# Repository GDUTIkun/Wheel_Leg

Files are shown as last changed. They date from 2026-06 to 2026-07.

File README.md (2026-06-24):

# wheel_leg_project

当前仓库已按以下层次收口：

- `ros2_ws/`：正式 ROS2 工作区
- `firmware/`：STM32 固件
- `sim/`：MuJoCo 资源
- `scripts/`：统一 build/run 入口
- `docs/`：结构和迁移文档
- `transplant/`：迁移参考区

ROS2 构建产物固定放在 `ros2_ws/` 下：

- `ros2_ws/build`
- `ros2_ws/install`
- `ros2_ws/log`

这样 `ros2_ws/` 只承担 ROS2 workspace 职责，避免和 `firmware/`、`sim/`、`scripts/` 混放。

常用命令：

```bash
./scripts/build.sh core
./scripts/build.sh sim
./scripts/build.sh pi
./scripts/run_host.sh sim
./scripts/run_host.sh sim_only
./scripts/run_pi.sh rc
./scripts/run_pi.sh hw
```

完整文档入口见：

- [docs/README.md](docs/README.md)

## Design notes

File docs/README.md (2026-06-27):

# 文档入口

当前 `docs/` 只保留正在使用的主线文档。历史迭代拆分、旧任务清单和重复规划文档已经移除，避免后续按过期内容继续推进。

## 当前主线

- `progress.md`：当前阶段进度与待确认问题。
- `stm32_hardware_integration.md`：STM32 硬件接入与实机闭环准备。
- `stm32_ros_comm_task.md`：STM32 与 ROS 第一版通信内容、字段和验收任务。
- `control_stm_migration_plan.md`：控制层接入 STM 的分层、阶段开关、测试顺序和进度表。
- `hardware_control_200hz.md`：当前 `200Hz` 实机控制口径、参数修改和频率说明。
- `100hz_balance_notes.md`：500Hz 调整到 100Hz 后的仿真平衡记录，作为上硬件前参考基线。
- `leg_angle_mapping.md`：腿部 GIM6010 电机角度到机构角/世界水平角的标定映射。

## 长期约束

- `architecture.md`：仓库结构、ROS2 包边界、仿真/实机切换原则。
- `protocol.md`：仿真和实机共用的 Topic、命名、单位、方向和通信边界。
- `runbook.md`：构建、启动和常用运行入口。

## 维护规则

- 新阶段只更新 `progress.md` 和对应的当前任务文档。
- 已完成阶段只保留对后续调试仍有直接价值的总结。
- 不再新增 `docs/doc/` 这类平行文档体系。

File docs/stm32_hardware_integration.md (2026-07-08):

# STM32 硬件接入与实机闭环任务

## 1. 任务目标

在 100Hz 仿真平衡基线已经可以站稳的基础上，进入 STM32 / 实机硬件接入阶段。

本任务的目标不是立刻完成最终实机参数，而是先打通真实硬件状态上报、控制命令下发、安全保护和基础方向校验，让后续 100Hz 实机调参有可靠输入。

## 2. 当前输入

- 100Hz 仿真可站立基线。
- `100hz_balance_notes.md` 中记录的传感器、滤波、LQR 和执行器输出处理原则。
- 已冻结的 RC 遥控输入与 failsafe 链路。
- 当前 ROS2 控制接口与仿真接口边界。
- STM32 侧电机、编码器、IMU 和底层安全保护能力。

## 3. 当前状态

- `[~]` 进入 STM32 / 实机硬件接入阶段。
- `[!]` 100Hz 仿真参数等待硬件接入后重新调参。

当前判断：

- 100Hz 仿真已能稳定站立，先作为可运行基线冻结。
- 当前不继续只在仿真中追求最终参数。
- 实机参数应在真实 IMU、编码器、电机响应和通信延迟接入后重新小步调整。

## 4. 重点任务

1. 通信链路
   - Raspberry Pi 与 STM32 的通信收发稳定。
   - 能观察通信周期、丢包、超时和错误计数。

2. 状态上报
   - 编码器角度、角速度、电机反馈状态可映射到 ROS2。
   - IMU 姿态和角速度可映射到 ROS2。
   - 单位统一为控制器期望的 `rad`、`rad/s`、`m/s`、`N*m` 等口径。

3. 命令下发
   - `/joint_command` 能下发到 STM32。
   - 电机命令方向、限幅、斜率限制和停机行为可验证。
   - 控制器不直接依赖 STM32 协议细节。

4. 安全保护
   - 通信超时进入安全状态。
   - 遥控 failsafe 可以阻断或降级控制输出。
   - 电机输出有明确最大值和变化率限制。
   - 初次调试支持悬空、低力矩、单关节验证。

5. 100Hz 实机闭环准备
   - 实测控制周期接近 `0.01s`。
   - 周期抖动可记录。
   - 传感器滤波和速度估计使用实际 `dt`。

## 5. 上硬件前检查

上硬件前至少确认：

- pitch 正方向与仿真一致。
- pitch_rate 正方向与 LQR 状态定义一致。
- 当前角度解算口径：角度由角速度积分得到；实机观测为向左转动角度正向增加，向右转动角度反向减小。
- 左右腿 `phi` 与 `phi_rate` 方向一致。
- 轮子前进方向与 `base_link.velocity` 正方向一致。
- STM32 上报的髋关节和小腿角已经是世界坐标系 absolute 角，bridge 不再叠加仿真 offset。
- `/robot_state` 中 `hip_absolute`、`calf_absolute` 与实物世界角一致。
- VMC 输出到电机后的力矩方向正确。
- 电机最大力矩和变化率不比仿真基线更激进。
- 控制使能前，滤波器状态能初始化到当前测量值。
- 急停、failsafe、通信超时都有可验证行为。

## 6. 初期调参原则

- 先悬空验证方向，再轻触地验证支撑力，最后再尝试站立。
- 先小力矩、小命令、短时间闭环，不直接恢复完整速度和转向能力。
- 先确认 `pitch_rate`、`phi_rate`、`base_velocity` 可信，再调 LQR 增益。
- 若出现 pitch 高频震荡，优先检查 IMU 方向、gyro 滤波、`pitch_rate` 增益和执行器斜率限制。
- 若出现缓慢前后跑偏，优先检查 `target_phi`、`target_pitch`、速度方向和距离积分。
- 若出现单侧压低，优先检查左右腿角度、roll、VMC 映射和左右电机方向。
- 若出现“仅单侧在某一方向或接近 `phi_target` 时更容易高频抖动”，不要只检查力矩极性；应同时记录该侧 `phi_rate`、髋膝关节速度和 `/joint_command`，优先排查目标附近闭环阻尼、单边速度状态过大、速度估计噪声、执行死区、机械回差或线束干涉。

## 7. 每轮记录模板

```text
- 轮次：
- 硬件状态：
- 修改参数/代码：
- 测试动作：
- 观察数据：
- 安全状态：
- 结论：
- 下一步：
```

## 8. 阶段完成标准

- STM32 通信链路稳定可观测。
- 真实传感器状态与 ROS2 状态接口语义一致。
- 电机命令方向、单位、限幅和安全停机已验证。
- 100Hz 实际控制周期和 `dt` 处理已确认。
- 可以在低风险条件下进入实机站立闭环参数调整。

## 9. 通信完成后的测试方法与流程

通信测试完成后，当前阶段不直接进入整机闭环，而是先做“悬空低力矩单关节验证”。

目标：

- 验证 `/joint_command -> bridge -> STM32 -> 电机` 下行链路持续有效。
- 验证六电机方向、单位、限幅和停机行为。
- 验证 `/joint_states`、`/imu`、`/robot_state` 的上行观测与实际动作一致。
- 验证 `RC ch7` 急停、命令超时和 bridge 侧状态监控工作正常。

### 9.1 测试前准备

执行前先确认：

- 机器人处于悬空或可靠支撑状态，轮子和腿部不会意外着地。
- 电机周围无工具、线缆和手部干涉。
- 树莓派与 STM32 已共地。
- 串口设备仍为 `/dev/ttyAMA4`，STM32 对应 `USART2`。
- 遥控器已上电，`RC ch7` 急停动作明确可用。
- bridge、STM32 固件和当前协议版本一致。
- 首次测试保持小力矩，例如 `0.1 ~ 0.2 N*m`。

### 9.2 启动流程

1. 启动正式 bridge，但先关闭控制器，避免 `/joint_command` 被控制器覆盖：

```bash
ros2 launch wheel_leg_bringup hw.launch.py use_controller:=false command_enable:=true
```

2. 在第二个终端观察 bridge 状态：

```bash
ros2 topic echo /stm32_bridge/status_text
```

3. 在第三个终端观察 bridge 计数器：

```bash
ros2 topic echo /stm32_bridge/counters
```

4. 在第四个终端观察关节反馈：

```bash
ros2 topic echo /joint_states
```

5. 如需同时观察机体状态，可额外打开：

```bash
ros2 topic echo /robot_state
```

### 9.3 单关节低力矩命令发送

当前推荐使用 `joint_command_probe_node` 做单关节验证。

固定正向小力矩示例：

```bash
ros2 run wheel_leg_stm32_bridge joint_command_probe_node --ros-args \
  -p joint_name:=left_hip \
  -p effort_nm:=0.2 \
  -p publish_rate_hz:=20.0 \
  -p mode:=constant
```

正负交替方波示例：

```bash
ros2 run wheel_leg_stm32_bridge joint_command_probe_node --ros-args \
  -p joint_name:=left_hip \
  -p effort_nm:=0.2 \
  -p publish_rate_hz:=20.0 \
  -p mode:=square \
  -p square_period_sec:=2.0
```

参数说明：

- `joint_name`：目标关节名，只允许规范名
- `effort_nm`：目标力矩幅值，建议从 `0.1` 或 `0.2` 开始
- `publish_rate_hz`：重复下发频率，当前建议 `20Hz`
- `mode=constant`：持续给定单一方向力矩
- `mode=square`：按周期在正负力矩之间切换
- `square_period_sec`：方波完整周期

### 9.4 推荐测试顺序

建议按以下顺序逐个测试，每次只动一个关节，其余五路保持零力矩：

1. `left_hip`
2. `left_knee`
3. `left_wheel`
4. `right_hip`
5. `right_knee`
6. `right_wheel`

每个关节建议按同样步骤执行：

1. 先用 `mode=constant` 验证正向小力矩。
2. 观察动作方向与 `/joint_states.velocity` 正方向是否一致。
3. 再改成负向小力矩，确认反向动作。
4. 最后用 `mode=square` 做短时间正负切换，观察限幅、响应和停机恢复是否稳定。

### 9.5 现场观察项

每轮测试至少观察以下内容：

- `/stm32_bridge/status_text` 中应保持 `state=ok`、`state_stale=false`
- `/stm32_bridge/counters` 中 `rx_frames_ok` 应持续增长
- `/stm32_bridge/counters` 中 `rx_crc_errors`、`rx_length_errors`、`rx_sync_losses` 不应明显持续增长
- `/joint_states` 中目标关节的位置和速度应与实际动作一致
- `/robot_state` 中与该动作相关的量不应出现明显跳变或异常漂移
- 若切到反向力矩，实际动作和速度符号也应同步反向
- 目标关节外的其他五个关节不应出现危险联动

### 9.6 安全项验证

在单关节方向确认后，必须补做以下安全验证：

1. 急停验证

- 维持单关节小力矩输出。
- 触发 `RC ch7` 急停。
- 预期行为：
  - bridge 状态中的 `estop=true`
  - 下行 `enable=0`
  - 电机输出立即归零或失能
  - 关节停止继续加速

2. 命令超时验证

- 关闭 `joint_command_probe_node`。
- 在 STM32 命令超时窗口后观察：
  - `safety=timeout` 或等价安全状态出现
  - 电机输出归零或失能
  - `last_command_timeout` 相关状态可观测

3. 限幅与斜率限制验证

- 将 `effort_nm` 从 `0.1` 逐步增加到 `0.2`、`0.3`
- 不直接大步跳到高力矩
- 观察实际响应是否平滑，是否存在异常冲击

### 9.7 异常时处理顺序

若测试中出现异常，按以下顺序排查：

1. 立即触发急停或关闭探针节点。
2. 确认机器人仍保持悬空和安全状态。
3. 查看 `/stm32_bridge/status_text` 是否变为 `state_stale=true`、`safety=timeout`、`estop=true` 等。
4. 查看 `/stm32_bridge/counters` 是否出现 CRC、长度、同步错误快速增长。
5. 若动作方向与预期相反，先记录关节名、正负力矩方向、实际动作方向，再回到映射层修正。
6. 若目标关节不动但计数器正常，优先排查 STM32 执行层、限幅、使能位和电机在线状态。
7. 若上行状态异常漂移，优先排查编码器零点、方向、IMU 方向和单位映射。

### 9.8 单轮记录建议

每个关节验证完成后，建议按下面格式记录：

```text
- 轮次：left_hip constant +0.2Nm
- 硬件状态：悬空 / 共地正常 / UART4<->USART2
- 修改参数/代码：无
- 测试动作：20Hz 持续下发 left_hip +0.2Nm
- 观察数据：joint_states.velocity 为正，bridge counters 正常
- 安全状态：RC ch7 急停有效，停止后 timeout 生效
- 结论：left_hip 正方向确认
- 下一步：验证 left_hip -0.2Nm 和 square 模式
```

### 9.9 2026-06-25 极性测试记录

本轮已完成一次六电机悬空极性验证，测试期间 bridge 通信保持正常，验证后已手动停机。

记录如下：

```text
- 日期：2026-06-25
- 硬件状态：机器人悬空 / UART4<->USART2 正常 / bridge state=ok
- 修改参数/代码：
  - 不修改 STM32 侧代码
  - 在 ROS bridge 下行命令路径加入轮子力矩极性修正
  - 修改文件：
    ros2_ws/src/wheel_leg_stm32_bridge/src/stm32_bridge_node.cpp
  - 新增下行符号表 kCommandEffortSigns
  - 轮子修正前：
    left_wheel=+1
    right_wheel=+1
  - 轮子修正后：
    left_wheel=-1
    right_wheel=-1
- 测试方式：
  - 使用 joint_command_probe_node 逐个关节下发恒定力矩
  - 六电机验证采用每路持续 5s 的方式现场观察转向
  - 轮子为便于观察，单独补做了 5s、6s、10s 的重复测试
- 现场结论：
  - 极性测试完毕
  - 轮子最终不修改 STM32 侧代码，只在 ROS bridge 下行力矩处做极性修正
  - 当前 ROS->STM32 下行力矩符号表为：
    left_hip=+1
    left_knee=+1
    left_wheel=-1
    right_hip=+1
    right_knee=+1
    right_wheel=-1
  - 对应实现位置：
    ros2_ws/src/wheel_leg_stm32_bridge/src/stm32_bridge_node.cpp
- 安全状态：
  - 每轮测试结束后 probe 节点退出
  - bridge 在测试完成后手动停止
  - 测试窗口内未观察到 bridge CRC / 长度 / 同步错误持续增长
```

后续若继续修正髋、膝或轮子的方向定义，应优先修改 ROS bridge 的下行力矩符号表，不直接把安装方向差异泄漏到上层控制器。

### 9.10 2026-06-25 RC / Timeout / 状态频率验收记录

本轮补做了通信部分剩余三项验收：`RC ch7` 急停整链、命令超时链路、以及 `/robot_state` `/imu` `/joint_states` 的时间戳与频率检查。

记录如下：

```text
- 日期：2026-06-25
- 前提修正：
  - RC 急停方向改为“高位急停”
  - estop.active_below 默认值由 true 改为 false
  - estop.threshold 默认值由 1500.0 调整为 1700.0
  - rc.launch.py 增加 estop_threshold launch 参数
  - 曾出现一次 RC 链路异常，现场确认为树莓派供电不足；恢复供电后重测
  - 曾出现 /rc/status 双发布者污染；清理重复 rc.launch 后按单发布者结果验收

- RC ch7 -> /rc/status.estop_active -> bridge -> STM32 safety_state：
  - 持续命令下抓到 bridge 状态从 safety=enabled 切换到 safety=estop
  - 同时 /rc/status.estop_active 与 bridge status_text 中 estop=true 对应变化一致
  - 该整链硬件验证通过

- 命令超时链路：
  - 在 estop_active=false 前提下，先持续发送单关节小力矩命令约 3s
  - bridge status_text 先进入：
    state=ok state_stale=false command_stale=false command_enable=true safety=enabled estop=false
  - 停止发送命令后，bridge status_text 回到：
    state=ok state_stale=false command_stale=true command_enable=true safety=timeout estop=false
  - 说明 STM32 命令超时保护链路工作正常，该项验收通过

- /robot_state /imu /joint_states 时间戳与频率：
  - /robot_state:
    header_dt_mean ≈ 0.01524 s
    approx_hz ≈ 65.99 Hz
  - /imu:
    header_dt_mean ≈ 0.01524 s
    approx_hz ≈ 65.65 Hz
  - /joint_states:
    header_dt_mean ≈ 0.01524 s
    approx_hz ≈ 65.62 Hz
  - 当前状态发布频率约 66 Hz，未达到 100 Hz / 0.01 s 目标
  - 该项结论应记录为“当前口径已测得，但仍需后续优化到 100 Hz 目标”

- RC 链路复查：
  - 在最终 10s 稳定窗口内：
    estop_active=false
    failsafe=false
    serial_online=true
    receiver_online=true
    frame_timeout=false
  - checksum_error_count 未增长
  - frame_sync_loss_count 未增长
```

当前通信部分剩余结论：

- `RC ch7` 急停整链：已验证通过
- 命令超时链路：已验证通过
- 状态发布时间戳 / dt / 频率：已测得当前约 `66 Hz`，但尚未达到 `100 Hz`

### 9.11 通过标准

通信完成后的这一步，至少满足以下条件才进入下一阶段：

- 六个关节都完成单关节小力矩方向验证
- `/joint_states` 与实际运动方向一致
- bridge 计数器在测试窗口内稳定
- 急停和命令超时都已验证
- 未出现危险联动、异常冲击或持续通信错误

满足以上条件后，再进入“轻触地验证”和后续低风险实机闭环调参。

### 9.12 2026-06-26 ROS 侧关节限位高力矩急停保护

本轮在 ROS bridge 侧补充了一条本地保护，不修改 STM32 侧代码。

记录如下：

```text
- 日期：2026-06-26
- 修改位置：
  ros2_ws/src/wheel_leg_stm32_bridge/src/stm32_bridge_node.cpp
- 触发条件：
  - 使用 STM32 状态帧回传的实际 joint_position / joint_effort 做判断
  - 当关节到达限位，并且该关节实际回传力矩绝对值 > 3.0 Nm 时
  - ROS bridge 触发本地 local estop，并立即向 STM32 下发 estop 命令帧
- 当前默认限位口径：
  - hip 使用世界角：
    left_hip  = 75 ~ 200 deg
    right_hip = 75 ~ 200 deg
  - knee 使用相对角，不叠加 hip：
    left_knee_relative  = -140 ~ -70 deg
    right_knee_relative = -140 ~ -70 deg
- 默认阈值来源：
  - docs/leg_angle_mapping.md
  - 其中明确记录：
    hip_world_range = 75 ~ 200
    knee_relative_range = -140 ~ -70
- 当前实现说明：
  - 该保护为 ROS 侧锁存急停；触发后即使后续命令继续下发，也会继续按 estop 发送
  - /stm32_bridge/status_text 会额外显示：
    local_estop=true
    local_estop_reason=...
  - 当前未实现自动解除，需要重启节点或后续再补显式复位机制
```

当前这条保护的目的不是替代 STM32 侧安全停机，而是在 ROS 侧增加一层“到限位仍持续顶力矩”的联调保护，降低悬空调试和轻触地调试阶段的风险。

### 9.13 2026-07-07 LQR 调参收口记录

本轮在 LQR + VMC 悬空方向复核完成后，对目标附近腿角闭环做保守化处理，并结束本轮 LQR 调参。

记录如下：

```text
- 日期：2026-07-07
- 修改位置：
  ros2_ws/src/wheel_leg_control/src/legacy_algorithms.cpp
  ros2_ws/src/wheel_leg_control/src/controller_node.cpp
  ros2_ws/src/wheel_leg_bringup/config/control_hw.yaml
- LQR 状态顺序：
  [phi, phi_rate, distance, velocity, pitch, pitch_rate]
- 输出语义：
  - 第一行取反后作为 VMC 腿摆杆虚拟力矩
  - 第二行作为轮端力矩
- 调参收口：
  - 髋部输出行的 phi / phi_rate 增益乘 0.6
  - 轮端输出行不乘该系数
  - 新增 phi_rate_damping_kd，硬件默认 -0.2
  - phi_rate_damping_kd 只追加到髋部虚拟力矩，不作用于轮端力矩
- 验证：
  - wheel_leg_control 单元测试通过
  - 新增测试覆盖“phi/phi_rate 缩放只影响髋部输出行”和“phi_rate_damping_kd 不影响 wheel_torque”
- 结论：
  - 本轮 LQR 调参结束
  - 后续轻触地/落地阶段不继续盲目改 LQR 增益
  - 若仍有目标附近局部抖动，优先查速度估计、执行死区/回差、静摩擦释放、线束干涉、限幅和斜率限制
```

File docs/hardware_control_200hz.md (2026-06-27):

# `200Hz` 实机控制口径记录

本文档记录自 `2026-06-27` 起，仓库主线硬件闭环采用的 `200Hz` 控制口径，避免继续把“`100Hz` 仿真基线”和“`200Hz` 实机联调口径”混在一起。

## 1. 当前结论

- STM32 `Data_Task` 以 `5ms` 周期运行，对应 `200Hz`。
- STM32 正式状态帧 `type=0x81` 已实测稳定跑到 `200Hz`。
- ROS 侧 `wheel_leg_stm32_bridge` 收到一帧状态就立即发布一次：
  - `/robot_state`
  - `/imu`
  - `/joint_states`
- ROS 侧 `wheel_leg_controller` 由 `/robot_state` 驱动，每收到一个满足 `dt` 条件的新样本就执行一步控制，并发布一次 `/joint_command`。
- 当前硬件参数已切到 `expected_dt_sec = 0.005`，即按 `200Hz` 接受控制样本。

## 2. 本次落地修改

本次仅切换**硬件主线**到 `200Hz`：

- 修改文件：`ros2_ws/src/wheel_leg_bringup/config/control_hw.yaml`
- 修改内容：
  - `debug_plot_publish_hz: 200.0`
  - `expected_dt_sec: 0.005`
  - `accepted_dt_tolerance_sec: 0.002`

当前 `accepted_dt_tolerance_sec = 0.002` 的接受窗口为：

- 最小 `dt = 0.003s`
- 最大 `dt = 0.007s`

该窗口用于覆盖串口、ROS 调度和时间戳抖动，但仍明确拒绝明显偏离 `200Hz` 主线的样本。

## 3. 当前频率口径

### 3.1 STM32 侧

- IMU 快照读取：`200Hz`
- 正式状态帧上报：`200Hz`
- 控制命令执行刷新：跟随下行 `/joint_command` 更新

### 3.2 ROS 硬件链

- `/robot_state`：约 `200Hz`
- `/imu`：约 `200Hz`
- `/joint_states`：约 `200Hz`
- `wheel_leg_controller` 有效控制步频：目标 `200Hz`
- `/joint_command`：目标 `200Hz`

### 3.3 RC 链

- `rc_ibus_node` 串口轮询周期：`5ms`，约 `200Hz`
- `/rc/channels_raw`：随有效遥控帧发布，通常接近 `200Hz`
- `/cmd_vel`、`/control_mode`、`/body_cmd`：随有效遥控帧更新
- `/rc/status`：`100ms`，即 `10Hz`

## 4. 与 `100Hz` 仿真基线的关系

以下内容**保持不变**：

- `100hz_balance_notes.md` 仍然是当前仿真平衡基线
- `control_sim.yaml` 仍按 `expected_dt_sec = 0.01` 运行
- MuJoCo 仿真主线仍是 `100Hz`

也就是说，当前仓库口径变为：

- 仿真主线：`100Hz`
- 实机硬件闭环主线：`200Hz`

后续如果需要把仿真也切到 `200Hz`，应单独立项，不要直接复用这次硬件参数切换结论。

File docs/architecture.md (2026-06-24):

# 轮腿机器人工程结构整改架构文档

## 1. 文档目标

本文档用于固定 STM32 接入前的正式工程结构，约束仓库目录、ROS2 包边界、构建入口和仿真/实机切换方式。

本文档服务于两个直接目标：

- 多设备同步同一仓库进度，但不同设备只构建自己需要的部分。
- 在不重写控制主链的前提下，为后续仿真/实机顺滑切换和 `ros2_control` 接入预留结构。

## 2. 总体原则

- 采用单仓库组织，不拆分为多个仓库。
- ROS2 代码统一收口到 `ros2_ws/src/`。
- 固件、仿真资源、脚本、文档与 ROS2 包分层存放。
- `transplant/` 仅作为迁移参考区，不承载新增正式能力。
- 当前阶段继续保持 Topic 闭环主线，不在本轮直接重构为完整 `ros2_control`。

## 3. 目标目录结构

```text
wheel_leg_project/
├── ros2_ws/
│   ├── src/
│   │   ├── wheel_leg_msgs/
│   │   ├── wheel_leg_control/
│   │   ├── wheel_leg_bringup/
│   │   ├── wheel_leg_hw/
│   │   ├── wheel_leg_stm32_bridge/
│   │   ├── wheel_leg_sim/
│   │   ├── wheel_leg_rc/
│   │   ├── wheel_leg_common/
│   │   └── wheel_leg_bridge/
│   ├── build/
│   ├── install/
│   └── log/
├── firmware/
│   └── stm32/
├── sim/
│   └── mujoco/
│       ├── runtime/
│       ├── models/
│       ├── scenes/
│       ├── assets/
│       └── README.md
├── scripts/
│   ├── build.sh
│   ├── run.sh
│   ├── flash_stm32.sh
│   └── env.sh
├── docs/
│   ├── README.md
│   ├── architecture.md
│   ├── protocol.md
│   ├── runbook.md
│   ├── progress.md
│   ├── stm32_hardware_integration.md
│   └── 100hz_balance_notes.md
├── transplant/
└── README.md
```

## 4. 各层职责

### 4.1 `ros2_ws/`

ROS2 正式开发工作区。

约束：

- 所有正式 ROS2 包只放在 `ros2_ws/src/`。
- `build/ install/ log/` 只存在于 `ros2_ws/` 内。
- 不在仓库根目录直接堆放新的 ROS2 包。

### 4.2 `firmware/stm32/`

STM32 固件区。

职责：

- 存放 STM32 工程、驱动、中断、协议处理和板级配置。
- 作为树莓派侧通信协议的对端实现。

约束：

- 不放 ROS2 包。
- 不放 MuJoCo 仿真逻辑。

### 4.3 `sim/mujoco/`

MuJoCo 模型和场景资源区。

职责：

- `runtime/`：MuJoCo 可执行仿真程序源码与构建入口。
- `models/`：机器人主体模型定义。
- `scenes/`：场景入口文件。
- `assets/`：网格、材质和贴图等资源。

约束：

- 仿真资源和 ROS2 包解耦。
- 不把模型文件继续埋在 `transplant/` 里作为正式入口。
- 不把仿真程序入口继续留在 `transplant/` 里。

### 4.4 `scripts/`

统一开发入口。

职责：

- 统一 `build` 和 `run` 的用户操作。
- 按设备和场景选择性构建。
- 固化环境变量和常用命令，降低协作摩擦。

### 4.5 `docs/`

正式文档区。

职责：

- 维护结构、协议、运行入口、当前进度和当前阶段任务文档。
- 保留对后续硬件接入仍有直接价值的调参记录。
- 不再维护旧的 `docs/doc/` 平行规划体系。

### 4.6 `transplant/`

迁移参考区。

职责：

- 保留旧 MuJoCo 工程、算法参考、早期实验材料。

约束：

- 不继续往这里写正式新代码。
- 默认不作为正式构建入口。

## 5. ROS2 包职责

### 5.1 `wheel_leg_msgs`

- 维护自定义消息。
- 统一 `/joint_command`、`/robot_state`、遥控相关消息定义。

### 5.2 `wheel_leg_control`

- 维护控制编排、状态处理、控制算法调用。
- 长期不直接依赖 MuJoCo API、串口实现、STM32 协议细节。

### 5.3 `wheel_leg_bringup`

- 维护 launch、参数装配、仿真/实机入口切换。
- 负责把同一套控制主链接到不同 backend。

### 5.4 `wheel_leg_hw`

- 维护统一硬件抽象。
- 固定 joint、imu、actuator 的命名、单位和语义。
- 作为后续 `ros2_control` 接口收口点。

### 5.5 `wheel_leg_stm32_bridge`

- 维护树莓派与 STM32 的通信节点。
- 负责协议编解码、状态上送、控制命令下发。

### 5.6 `wheel_leg_sim`

- 维护 MuJoCo 运行时适配。
- 负责仿真状态采样、命令写入和 sim-only helper。

### 5.7 `wheel_leg_rc`

- 维护遥控器输入接入与统一命令发布。

### 5.8 `wheel_leg_common`

- 维护共享类型、数学工具、命名映射和轻量公共结构。

### 5.9 `wheel_leg_bridge`

- 保留现有消息转换和通信边界胶水代码。
- 在过渡期继续服务现有主链。

## 6. 控制主链与切换原则

当前阶段统一主链固定为：

```text
state source -> /robot_state -> wheel_leg_controller -> /joint_command -> actuator sink
```

### 6.1 仿真模式

- `wheel_leg_sim` 发布 `/robot_state`
- `wheel_leg_controller_node` 订阅 `/robot_state`
- `wheel_leg_controller_node` 发布 `/joint_command`
- `wheel_leg_sim` 消费 `/joint_command`

### 6.2 实机模式

- `wheel_leg_stm32_bridge` 发布 `/robot_state`
- `wheel_leg_controller_node` 订阅 `/robot_state`
- `wheel_leg_controller_node` 发布 `/joint_command`
- `wheel_leg_stm32_bridge` 消费 `/joint_command`

切换时不更换控制器，只更换状态源和命令去向。

## 7. 与 `ros2_control` 的关系

本轮不直接迁到完整 `ros2_control`，但结构必须为后续接入预留。

后续目标：

- MuJoCo 对接 `WheelLegMujocoSystem`
- STM32 对接 `WheelLegSTM32System`
- 控制器视情况迁成 controller plugin，或保留外部节点过渡

本轮必须先固定：

- joint 命名
- imu 命名
- actuator 命名
- 单位
- 方向
- 零位约定

## 8. 当前状态说明

当前仓库已经完成的结构性动作：

- 原 `src/` 已迁入 `ros2_ws/src/`
- 原 `build/ install/ log/` 已迁入 `ros2_ws/`
- 旧 `docs/doc/` 拆分文档已清理，当前只保留 `docs/` 根目录主线文档

后续重构应基于本文件继续推进，不再回到“根目录直接堆 ROS2 工作区产物”的方式。

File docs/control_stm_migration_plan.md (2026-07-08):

# 控制层接入 STM 迁移计划

## 1. 目标与边界

第一阶段采用 `ROS2 控制 + STM32 硬件后端`：

- `wheel_leg_control` 继续运行 VMC、LQR、航向、抗劈叉和 roll 补偿。
- `wheel_leg_stm32_bridge` 负责 STM32 协议编解码、状态映射、命令下发和 ROS 侧安全保护。
- `firmware/stm32` 负责真实传感器采样、电机执行、力矩限幅、斜率限制、命令超时和急停。
- 本阶段不把 VMC/LQR 下沉到 STM32，也不迁入完整 `ros2_control`。

公共主链保持不变：

```text
backend -> /robot_state -> wheel_leg_controller -> /joint_command -> backend
```

仿真和硬件只替换 backend：

- 仿真：`wheel_leg_sim` 发布 `/robot_state` 并消费 `/joint_command`
- 硬件：`wheel_leg_stm32_bridge` 发布 `/robot_state` 并消费 `/joint_command`

## 2. 分层与代码对应

| 层级 | 职责 | 主要代码 | 当前状态 |
| --- | --- | --- | --- |
| 控制阶段门控 | 按传感器、VMC、LQR、航向、抗劈叉、roll 逐段打开控制输出 | `wheel_leg_control` | `[v] LQR+VMC 悬空方向已验证，[~] 落地稳定性待验证` |
| 仿真参数入口 | 保持仿真全功能默认配置 | `wheel_leg_bringup/config/control_sim.yaml` | `[x] 代码已完成` |
| 硬件参数入口 | 当前硬件默认进入 LQR 阶段，VMC/LQR/腿长 PID/轮端/髋膝输出均开启，辅助环仍关闭 | `wheel_leg_bringup/config/control_hw.yaml` | `[x] 代码已完成，[~] 落地待验证` |
| 硬件状态装配 | 将 STM32 absolute 世界角/IMU 数据映射到控制器语义 | `wheel_leg_stm32_bridge/hardware_state_assembler` | `[x] 代码已完成，[!] 待实机验证` |
| STM32 协议与执行 | 状态帧、命令帧、限幅、斜率、超时、急停 | `wheel_leg_stm32_bridge` / `firmware/stm32` | `[~] 联调中` |

`wheel_leg_control` 不解析 STM32 二进制协议；STM32、串口、CAN 细节不得泄漏到控制层。

硬件腿部角度口径：

- 仿真侧仍由原始关节角叠加 offset 得到 `hip_absolute`、`calf_absolute`。
- STM32 上报到 bridge 的髋和小腿角已经是世界坐标系 absolute 角，bridge 不再叠加仿真 offset。
- 状态帧中的 `left_knee` / `right_knee` 位置槽位在控制语义里作为 `left_calf_absolute` / `right_calf_absolute` 使用。
- 腿部机构不是串联二连杆，不能使用 `hip_absolute + calf_absolute - pi` 推下连杆角。
- 腿部几何按实物平行四边形语义计算：`delta = hip_absolute - calf_absolute`，`knee_angle = pi - delta`，`lower_link_absolute = hip_absolute - pi + knee_angle`，再用大小腿三角形求腿对角边 `leg_length` 与世界系腿角 `phi`。
- `phi_rate` 由修正后的 `phi` 做角度差分和低通滤波。
- VMC 的髋/膝力矩映射已按同一套几何复核，避免 `phi/leg_length` 已修正但雅可比仍沿用旧串联模型。

## 3. 控制阶段参数

控制器新增以下参数，仿真默认全开；当前硬件默认配置已进入 LQR 阶段：

- 已开启：`VMC`、`LQR`、腿长 PID、轮端输出、髋/膝输出。
- 仍关闭：航向控制、抗劈叉、roll 补偿。
- `hw.launch.py` 默认 `command_enable=false`，即 ROS 内部会计算 `/joint_command`，但 bridge 不会向 STM32 下发实际非零力矩，除非显式改为 `command_enable:=true`。

| 参数 | 作用 | 硬件默认 |
| --- | --- | --- |
| `enable_vmc` | 启用腿端力/髋力矩到髋膝电机力矩的 VMC 映射 | `true` |
| `enable_lqr` | 启用 LQR 计算轮端力矩和髋关节虚拟力矩 | `true` |
| `enable_leg_length_pid` | 启用腿长 PID 和重力补偿 | `true` |
| `enable_heading_control` | 启用航向/yaw rate 控制与转向髋前馈 | `false` |
| `enable_anti_split` | 启用左右腿 `phi` 差的抗劈叉控制 | `false` |
| `enable_roll_compensation` | 启用 roll 平衡补偿 | `false` |
| `enable_wheel_output` | 允许发布左右轮力矩 | `true` |
| `enable_hip_output` | 允许发布左右髋力矩 | `true` |
| `enable_knee_output` | 允许发布左右膝力矩 | `true` |
| `phi_rate_damping_kd` | 在 LQR 髋部虚拟力矩处追加 `phi_rate * kd`，不作用于轮端力矩 | `-0.2` |
| `target_leg_length_min` | 实物侧腿长目标下限，单位 m | `0.15` |
| `target_leg_length_max` | 实物侧腿长目标上限，单位 m | `0.32` |
| `target_phi_min_deg` | 实物侧腿角目标下限，单位 deg | `30.0` |
| `target_phi_max_deg` | 实物侧腿角目标上限，单位 deg | `150.0` |

运行时可用 `ros2 param set /wheel_leg_controller <参数名> true/false` 逐段切换。

## 4. 推荐实机测试顺序

### 4.1 传感器阶段

目标：只验证 STM32 上行状态，不闭环控制。

启动：

```bash
ros2 launch wheel_leg_bringup hw.launch.py use_controller:=false command_enable:=false
```

观察：

- `/joint_states`
- `/imu`
- `/robot_state`
- `/stm32_bridge/status_text`
- `/stm32_bridge/counters`

确认项：

- `pitch`、`pitch_rate`、`roll`、`yaw_rate` 方向和单位正确。
- STM32 上传的 `hip` / `calf` 世界角无需二次 offset，`/robot_state` 中 `*_hip_absolute` 和 `*_calf_absolute` 应与实物世界角一致。
- `phi`、`phi_rate` 左右一致，且与 LQR 状态定义一致。
- `body_velocity` 与轮子前进方向一致。
- `/robot_state` 时间戳稳定，控制周期可接近 `0.01s`。

### 4.2 VMC 阶段（已完成）

目标：验证腿长力到髋/膝力矩映射，并完成进入 LQR 前的腿长控制闭环。

该阶段的历史验证模式：

- 裸启动 `wheel_leg_controller` 时，默认就是“腿长 PID + VMC”。
- `hw.launch.py` 对应的 `control_hw.yaml` 也已改成同样配置。
- 当时仅保留腿长 PID、VMC 和髋/膝电机输出，用于单独确认腿长闭环与 VMC 映射。
- 2026-07-07 当前硬件默认已进入 LQR + VMC 联合阶段：`enable_vmc=true`、`enable_lqr=true`、`enable_wheel_output=true`、`enable_hip_output=true`、`enable_knee_output=true`。

建议参数：

```bash
ros2 param set /wheel_leg_controller enable_hip_output true
ros2 param set /wheel_leg_controller enable_knee_output true
```

该阶段仅作为回溯记录，不作为当前硬件默认配置；当前默认见第 3 节。

确认项：

- 悬空低力矩下髋/膝力矩方向正确。
- 支撑力趋势正确。
- 急停、超时、限幅和斜率限制工作正常。

调参顺序：

1. 先固定 `target_leg_length`，不要一边改目标一边调 PID。
2. 先调 `leg_length_pid.kp`，让腿能“跟上”目标，但不出现连续上下弹跳。
3. 再调 `leg_length_pid.kd`，专门压制落地后或抬放腿时的振荡。
4. 最后再少量加入 `leg_length_pid.ki`，只用于消除静差，不用于“顶起”机器人。

观察重点：

- `leg_length` 能否稳定收敛到 `target_leg_length`
- `/debug/control/leg_length_output` 是否平滑，是否频繁顶到限幅
- 髋膝输出是否同向配合支撑，而不是一侧明显反着顶
- 落地后若出现高频抖动，优先减 `kp` 或加一点 `kd`
- 落地后若慢慢塌腿，再少量加 `ki`

实机建议：

- 第一轮把 `hip_effort_limit`、`knee_effort_limit` 保持在较小值，先确认方向对。
- 每次只改一个参数，单次改幅建议不超过 `10%` 到 `20%`。
- 若输出已频繁打满，先降 `kp`，不要继续加 `ki`。

当前进度补充：

- `2026-07-04` 已按该模式完成腿长控制阶段推进。
- 文档后续不再把 VMC 阶段视为“待开始”，当前主线已转入 LQR。

### 4.3 LQR 阶段

目标：在已完成腿长控制基础上，启用 VMC + LQR，验证平衡主环输出方向并逐步进入轻触地/短时落地联调。

建议参数：

```bash
ros2 param set /wheel_leg_controller enable_lqr true
ros2 param set /wheel_leg_controller enable_wheel_output true
```

保持：

- `enable_heading_control=false`
- `enable_anti_split=false`
- `enable_roll_compensation=false`

确认项：

- 先悬空观察轮端和髋关节输出符号。
- 再轻触地观察支撑趋势。
- 最后短时间落地，避免直接长时间闭环。

当前阶段关注：

- 优先确认 `pitch`、`pitch_rate`、`phi_rate`、`base_velocity` 和轮端输出符号一致。
- 若 LQR 打开后出现明显前后冲、轮子快速打满或髋部反向顶杆，先回头检查状态方向和滤波，再继续加大接地时间。

2026-07-07 实机复核结论：

- 本轮复核时必须保持 `command_enable:=false`，只观察 ROS 内部 `/joint_command` 与 debug topic，不让 STM32 执行力矩。
- MATLAB LQR 状态定义与 C++ 控制状态定义一致，状态顺序保持：

```text
[phi, phi_rate, distance, velocity, pitch, pitch_rate]
```

- 这里 `phi` 是腿摆杆角，对应 MATLAB 模型中的 `theta`；`pitch` 是机体倾角，对应 MATLAB 模型中的 `phi/varphi`。不要因为 MATLAB 符号名把两者换位。
- 本次 hip 力矩过小的真正原因不是状态顺序错，而是 LQR 两路输出语义接错：腿摆杆角恢复量主要在 LQR 第一行输出中，原 C++ 把它接到了 `wheel_torque`，导致送入 VMC 的 `hip_torque` 只有约 `0.03 ~ 0.05 Nm`。
- 修正后的映射为：LQR 第一行取反后作为 VMC 腿摆杆虚拟力矩，第二行作为 wheel 输出。
- VMC 映射按二连杆世界角重算腿长与腿角，再从虚拟腿长力/腿摆杆力矩映射到 hip/knee，避免上游 `leg_length/phi` 与关节角口径不一致时缩小 hip 输出。
- `hw.launch.py` 默认将 `joint_limit_protection.effort_threshold_nm` 设为 `0.0`，关闭 ROS bridge 的本地关节限位保护，避免只观察内部力矩时触发 local estop。

实测验证，`command_enable=false`、限位保护阈值 `0.0`：

```text
默认 target_phi=97.1 deg，当前 phi_c≈104.48 deg：
  right_hip≈-2.20 Nm, left_hip≈-1.17 Nm
  right_knee≈-5.21 Nm, left_knee≈-4.56 Nm

临时 target_phi=115 deg，当前 phi_c≈104.48 deg，即 phi_c < phi_target：
  right_hip≈+1.89 Nm, left_hip≈+2.85 Nm
  right_knee≈-2.85 Nm, left_knee≈-2.23 Nm
```

判据通过：`length_c > length_target` 时 knee 输出较大负力矩；`phi_c < phi_target` 时 hip 输出较大正力矩。

2026-07-07 LQR 调参收口：

- LQR 状态顺序和输出语义冻结：状态仍为 `[phi, phi_rate, distance, velocity, pitch, pitch_rate]`，第一行取反后作为 VMC 腿摆杆虚拟力矩，第二行作为轮端输出。
- 为降低目标附近腿角闭环激进程度，LQR 第一行中的 `phi` 与 `phi_rate` 两项增益统一乘以 `0.6`；轮端输出行的 `phi` / `phi_rate` 增益不乘该系数。
- 额外 `phi_rate_damping_kd` 只加在 LQR 髋部虚拟力矩处，当前硬件默认 `-0.2`。该项不进入 `wheel_torque`，避免把腿角速度阻尼混到轮端平衡力矩。
- 本轮不再继续扩大 LQR 增益调参范围。后续轻触地/落地测试若仍出现局部振荡，优先从速度估计质量、执行死区/回差、静摩擦释放、线束干涉和限幅/斜率限制排查；只有在这些现象被复核后再重新打开 LQR 增益调整。

### 4.4 落地稳定性阶段

目标：在低限幅下验证基础站立稳定性。

使用 `control_hw.yaml` 中的保守力矩限制作为起点：

- `hip_effort_limit: 3.0`
- `knee_effort_limit: 3.0`
- `wheel_effort_limit: 1.0`

观察：

- `/debug/control/balance`
- `/debug/control/wheel_effort`
- `/debug/control/leg_length_output`
- `pitch`、`pitch_rate`
- `phi`、`phi_rate`
- `body_velocity`

若出现 pitch 高频震荡，优先检查 IMU 方向、gyro 滤波、`phi_rate`、`base_velocity` 和执行器斜率限制。

2026-07-07 左腿单侧抖动实测补充：

- 当前右腿可正常控，左腿在 `phi` 增大方向更容易触发高频抖动。
- 调整 `phi_target` 后，抖动区间会跟随目标移动，不是固定出现在某个绝对机械角度。
- 单关节 probe 已确认左腿 `left_hip` / `left_knee` 下行力矩极性修正后与实物动作方向一致，因此当前问题不优先归因于命令极性。
- 采集脚本：`tools/left_leg_oscillation_capture.py`
- 当前实测中，`phi_increasing` 阶段左腿速度状态显著大于右腿：
  - `left_phi_rate max ≈ 6.00 rad/s`
  - `left_phi_rate_raw max ≈ 10.13 rad/s`
  - `raw_left_hip_vel max ≈ 7.32 rad/s`
  - `raw_left_knee_vel max ≈ 8.19 rad/s`
  - 同时 `right_phi_rate mean ≈ -0.013 rad/s`
- 当前优先级最高的排查方向：
  - 接近 `phi_target` 时，左腿 `phi_rate` 是否被髋/膝某一路速度单边放大
  - LQR 速度反馈或 VMC 映射在目标附近是否过激
  - 左腿执行侧是否存在死区、回差、静摩擦释放或线束干涉，导致目标附近小范围来回打

### 4.5 航向与抗劈叉阶段

目标：在基础站立可控后启用方向控制和左右腿约束。

建议参数：

```bash
ros2 param set /wheel_leg_controller enable_heading_control true
ros2 param set /wheel_leg_controller enable_anti_split true
```

确认项：

- 左右轮差速方向正确。
- 左右髋抗劈叉力矩方向正确。
- `left_phi - right_phi` 被拉回，而不是放大。

### 4.6 Roll 补偿阶段

目标：最后启用横滚补偿。

建议参数：

```bash
ros2 param set /wheel_leg_controller enable_roll_compensation true
```

确认项：

- 左右髋 roll 补偿方向正确。
- 不出现单侧持续压低。
- 关闭 roll 补偿后现象可复现退回，便于确认因果。

## 5. 验收与记录

每轮记录建议：

```text
- 轮次：
- 当前阶段：
- 启用参数：
- 硬件状态：
- 测试动作：
- 观察数据：
- 安全状态：
- 结论：
- 下一步：
```

阶段完成标准：

- `[v]` 传感器阶段：`/robot_state` 与真实姿态、关节、轮速方向一致。
- `[v]` VMC 阶段：髋/膝输出方向正确，低力矩下安全保护可验证。
- `[v]` LQR 阶段：轮端与髋关节平衡输出方向正确，可短时间低风险落地。
- `[v]` 落地稳定性阶段：低限幅下可维持基础站立或明确定位剩余方向/滤波/延迟问题。
- `[v]` 航向+抗劈叉阶段：差速与左右腿约束方向正确。
- `[v]` roll 阶段：横滚补偿方向正确，不引入单侧压低。

## 6. 自动验证

当前已加入自动测试：

- `wheel_leg_control/test/test_stand_control_pipeline.cpp`
  - 验证所有阶段开启时完整命令路径存在。
  - 验证所有阶段关闭时对应算法不被调用且输出为零。
  - 验证 wheel/hip/knee 输出组可单独门控。
- `wheel_leg_stm32_bridge/test/test_hardware_state_assembler.cpp`
  - 验证轮速到 `body_velocity/body_distance`。
  - 验证腿几何、`phi` 和 `phi_rate` 滤波。

建议每次修改控制门控或硬件状态装配后执行：

```bash
source ros2_ws/install/setup.bash
colcon --log-base ros2_ws/log build \
  --base-paths ros2_ws/src \
  --build-base ros2_ws/build \
  --install-base ros2_ws/install \
  --packages-select wheel_leg_control wheel_leg_stm32_bridge wheel_leg_bringup

colcon --log-base ros2_ws/log test \
  --base-paths ros2_ws/src \
  --build-base ros2_ws/build \
  --install-base ros2_ws/install \
  --packages-select wheel_leg_control wheel_leg_stm32_bridge
```

## 7. 当前进度

| 项目 | 状态 | 说明 |
| --- | --- | --- |
| 控制阶段参数与运行时切换 | `[x]` | 已接入 `wheel_leg_controller` |
| `RunStandControlStep` 阶段门控 | `[x]` | VMC/LQR/PID/航向/抗劈叉/roll/输出组已可单独关闭 |
| 仿真参数文件 | `[x]` | `control_sim.yaml` 默认全功能 |
| 硬件参数文件 | `[x]` | `control_hw.yaml` 当前默认开启 VMC/LQR/腿长 PID，`hw.launch.py` 默认关闭 bridge 本地限位保护 |
| launch 加载参数 | `[x]` | `sim.launch.py` / `hw.launch.py` 已加载各自参数 |
| 硬件状态 assembler | `[x]` | 已从 bridge 节点拆出并加测试 |
| 构建与单元测试 | `[v]` | `wheel_leg_control`、`wheel_leg_stm32_bridge`、`wheel_leg_bringup` 构建通过，新增测试通过 |
| 传感器阶段实机验证 | `[x]` | 已支撑腿长控制阶段推进，剩余问题转入 LQR 联调中继续复核 |
| VMC 阶段实机验证 | `[x]` | 腿长控制阶段已完成，当前已进入 LQR |
| LQR 阶段实机验证 | `[~]` | 已完成悬空方向复核并收口本轮 LQR 调参；仍需轻触地/落地验证 |
| 落地稳定性验证 | `[ ]` | 待现场测试 |
| 航向+抗劈叉验证 | `[ ]` | 待现场测试 |
| roll 补偿验证 | `[ ]` | 待现场测试 |

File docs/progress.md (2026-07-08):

# 当前任务进度

## 1. 当前迭代

- 迭代编号：`iter-005`
- 迭代名称：STM32 硬件接入与 200Hz 实机闭环联调
- 当前任务文档：`stm32_hardware_integration.md` / `stm32_ros_comm_task.md` / `control_stm_migration_plan.md` / `hardware_control_200hz.md`
- 100Hz 仿真基线：`100hz_balance_notes.md`

## 2. 状态说明

任务状态使用：

```text
[ ] 未开始
[~] 进行中
[x] 代码已完成
[!] 阻塞或待验证
[?] 待确认
[v] 已通过验证
```

注意：

- `[x] 代码已完成` 不等于 `[v] 已通过验证`。
- 本轮当前是硬件接入准备迭代，允许任务先停留在通信、方向、单位和安全验证阶段，不要求立即完成实机站立。
- 旧迭代拆分文档已清理，已完成能力只作为当前阶段输入，不在本轮重复验收实现细节。

## 3. 迭代目标概览

`iter-005` 关注：

- 固定 100Hz 仿真平衡阶段先冻结，等待硬件接入后再调最终参数。
- 建立 Raspberry Pi 与 STM32 的真实通信闭环。
- 对齐真实 IMU、编码器、电机状态与 ROS2 状态接口。
- 对齐 ROS2 控制命令到 STM32 电机执行命令的方向、单位、限幅和安全状态。
- 将当前硬件控制主线口径切换并固定为 `200Hz`。
- 固定实机初期按悬空、低力矩、轻触地、站立闭环的顺序推进。
- 完成腿长控制阶段，完成 LQR + VMC 悬空输出方向复核，转入轻触地/落地稳定性验证。

## 3.1 当前进度快照（2026-07-07）

当前实机主线状态：

- 通信链路：STM32 状态上报和 ROS bridge 已跑通，硬件主线按 `200Hz` 消费 `/robot_state`。
- 状态装配：`/robot_state` 已包含 IMU、轮端、腿部 `hip_absolute/calf_absolute`、`leg_length`、腿摆杆角 `phi` 和 `phi_rate`。
- 腿长控制：腿长 PID + VMC 阶段已完成，`length_c > length_target` 时 knee 输出较大负力矩。
- LQR + VMC：悬空方向复核已完成，`phi_c < phi_target` 时 hip 输出较大正力矩。
- 当前硬件默认控制：`enable_vmc=true`、`enable_lqr=true`、`enable_leg_length_pid=true`、`enable_wheel_output=true`、`enable_hip_output=true`、`enable_knee_output=true`。
- LQR 调参状态：本轮已收口；`phi` / `phi_rate` 髋部增益按 `0.6` 缩放，`phi_rate_damping_kd=-0.2` 仅作用于髋部虚拟力矩，轮端力矩不叠加该项。
- 当前仍关闭的辅助环：`enable_heading_control=false`、`enable_anti_split=false`、`enable_roll_compensation=false`。
- 安全口径：`hw.launch.py` 默认 `command_enable=false`；ROS bridge 本地关节限位保护阈值默认为 `0.0`，即关闭本地限位保护。真正上电输出前仍必须显式确认 `command_enable`。
- 当前新增问题：`left_hip` 在实机输出打开后存在单侧抖动；右腿可正常控，左腿在实际 `phi` 接近当前 `phi_target` 时更容易触发高频抖动，改变 `phi_target` 后抖动区间会跟随目标移动。
- 当前下一步：在冻结本轮 LQR 参数的前提下进入轻触地/落地稳定性验证；若左腿目标附近仍抖动，优先看左腿 `phi_rate` / 关节速度估计质量、执行死区/回差、静摩擦释放、线束干涉和输出限幅/斜率限制。

本轮已定位并修复的问题：

- LQR 状态顺序没有错，保持 `[phi, phi_rate, distance, velocity, pitch, pitch_rate]`。
- MATLAB 中 `theta` 是腿摆杆角，对应 C++ 的 `leg.phi`；MATLAB 中 `phi/varphi` 是机体倾角，对应 C++ 的 `body.pitch`。
- hip 力矩过小的原因是 LQR 两路输出语义接错：腿摆杆恢复量在 LQR 第一行，原先被接到 wheel，导致 VMC 收到的 hip 虚拟转矩只有 `0.03 ~ 0.05 Nm`。
- 当前修正为 `wheel_torque = lqr_output[1]`，`hip_virtual_torque_for_vmc = -lqr_output[0]`。
- LQR 髋部输出行的 `phi` 和 `phi_rate` 增益已乘 `0.6`，用于降低目标附近腿角闭环激进程度；轮端输出行不做该缩放。
- `phi_rate_damping_kd` 已加入运行时参数，硬件默认 `-0.2`，只追加到髋部虚拟力矩，不作用于轮端力矩。
- VMC 已改为按二连杆世界角重算腿长和腿摆杆角，再映射虚拟腿长力/腿摆杆力矩到 hip/knee。
- ROS bridge 下行力矩极性已再次按单关节 probe 复核，当前左腿 `left_hip`、`left_knee` 命令极性均取反后与实物方向一致。

最近一次 `command_enable=false` 实测：

```text
默认 target_phi=97.1 deg，当前 phi_c≈104.48 deg：
  right_hip≈-2.20 Nm, left_hip≈-1.17 Nm
  right_knee≈-5.21 Nm, left_knee≈-4.56 Nm

临时 target_phi=115 deg，当前 phi_c≈104.48 deg，即 phi_c < phi_target：
  right_hip≈+1.89 Nm, left_hip≈+2.85 Nm
  right_knee≈-2.85 Nm, left_knee≈-2.23 Nm
```

2026-07-07 左腿抖动补充结论：

```text
- 现象：
  - right_leg 可正常跟踪，left_hip 在输出打开后更容易抖动。
  - 只手动向 `phi` 增大方向拉左腿时，更容易触发抖动。
  - 修改 `phi_target` 后，抖动不是固定出现在某个绝对角度，而是在实际 `phi` 接近新的 `phi_target` 附近出现。
- 已排除：
  - left_hip / left_knee 下行力矩极性已通过单关节 probe 修正。
  - 左腿 `phi`、`phi_rate` 主方向与关节速度主方向大体一致，不是整条状态链完全反号。
- 当前观测：
  - 记录脚本：tools/left_leg_oscillation_capture.py
  - `phi_increasing` 样本中：
    left_phi_rate max ≈ 6.00 rad/s
    left_phi_rate_raw max ≈ 10.13 rad/s
    raw_left_hip_vel max ≈ 7.32 rad/s
    raw_left_knee_vel max ≈ 8.19 rad/s
  - 同时右腿基本接近静止：
    right_phi_rate mean ≈ -0.013 rad/s
    raw_right_hip_vel mean ≈ -0.018 rad/s
- 当前判断：
  - 控制器在 `phi` 增大时对 left_hip 的恢复力矩方向是对的，不像单纯极性错误。
  - 因抖动区间会随 `phi_target` 移动，当前不再优先认为是某个固定机械角度点的问题。
  - 更像目标附近的局部闭环振荡：左腿速度状态过大/过吵、执行死区/回差或小范围静摩擦释放均需排查。
  - LQR 本轮已按保守口径收口，下一步优先拆解 left_phi_rate 的来源，并在接近 `phi_target` 的小扰动窗口内对比 left/right 的 `phi_rate`、`cmd_hip` 与实际关节速度。
```

`iter-005` 不关注：

- 继续只在 MuJoCo 中追求最终参数。
- 在硬件状态未校验前直接完整站立。
- 在通信和安全链路未闭环前扩大速度、转向或高度范围。
- 遥控器输入接口重设计。
- 地面站 UI。
- 完整 `ros2_control` 落地。

## 4. 模块任务总览

| 模块任务 | 文件 | 当前状态 | 说明 |
| --- | --- | --- | --- |
| 遥控输入与命令映射 | `wheel_leg_rc` / `wheel_leg_control` | `[v] 已通过验证` | 已完成真实遥控器通道确认，`/cmd_vel`、`/control_mode`、`/body_cmd` 与 failsafe 映射已实机验证 |
| 仿真控制参数基线 | `100hz_balance_notes.md` | `[v] 阶段冻结` | 100Hz 仿真已可稳定站立，参数等待硬件接入后重新小步调整 |
| 腿部角度映射 | `leg_angle_mapping.md` | `[v] 速度已验证` | 已按现场观测修正左右髋和左右膝世界角；四个关节角速度极性已实机确认，knee 角速度已正确叠加 hip 角速度 |
| STM32 硬件接入任务 | `stm32_hardware_integration.md` | `[~] 进行中` | 当前已完成通信、状态装配、腿长控制和 LQR+VMC 悬空方向复核，主线转入轻触地/落地稳定性验证 |
| STM32 与 ROS 通信内容 | `stm32_ros_comm_task.md` | `[~] 首轮联调已完成，V1 代码已落地` | 第一版固定为串口通信；`2026-06-26` 已确认 STM 状态上报稳定 `200Hz`，`2026-06-27` 起 ROS 硬件控制口径同步切到 `200Hz` |
| 实机 200Hz 控制口径 | `hardware_control_200hz.md` | `[x] 已记录` | 已明确当前硬件主线为 `200Hz`，并记录控制器 `dt` 参数、topic 频率和仿真/实机口径分离原则 |
| 控制层接入 STM 分阶段迁移 | `control_stm_migration_plan.md` | `[~] 落地稳定性阶段进行中` | 已完成阶段开关、硬件状态装配、传感器基础联调、腿长控制、LQR+VMC 悬空方向复核 |
| 工程结构与接口约束 | `architecture.md` / `protocol.md` | `[~] 持续维护` | 保留为当前文档入口，不再维护旧 `docs/doc/` 规划体系 |

## 5. 推荐执行顺序

1. `[x]` 完成真实遥控器到仿真控制链的最小联调闭环。
2. `[x]` 固定仿真控制参数基线。
3. `[x]` 将 500Hz 控制频率下调到 100Hz，并在仿真中恢复站立稳定。
4. `[x]` 冻结 100Hz 仿真阶段，等待硬件接入后再调最终参数。
5. `[~]` 进入 STM32 硬件接入任务，先按 `stm32_ros_comm_task.md` 固定通信内容，再验证通信、状态、命令和安全链路。
6. `[x]` 为控制层接入 STM 建立阶段开关、仿真/硬件参数入口和硬件状态装配模块。
7. `[x]` 按 `control_stm_migration_plan.md` 完成进入控制前所需的传感器基础联调。
8. `[x]` 完成腿长控制阶段，已验证可进入下一阶段联调。
9. `[x]` 按 `control_stm_migration_plan.md` 完成 LQR + VMC 悬空输出方向复核。
10. `[~]` 按 `control_stm_migration_plan.md` 进入轻触地与落地稳定性验证。
11. `[ ]` 按 `control_stm_migration_plan.md` 完成航向+抗劈叉与 roll 补偿验证。

## 6. 当前输入与已完成基础

作为本轮输入，以下内容已存在：

- 当前架构已建立 `/joint_states`、`/imu`、`/joint_command` 和 `/robot_state` 边界。
- 当前控制链已完成控制编排外移、`sim adapter` 收口和 ROS2 接口接入。
- 当前第二阶段硬件事实已经明确：`FlySky FS-iA6B`、`iBUS`、`/dev/ttyAMA3`、`GPIO8/9`。
- 当前项目没有地面站，需要在 ROS2 环境中直接完成调参与观察。
- 当前已完成真实遥控器到仿真控制链联调，`stand`、`velocity`、failsafe 与恢复复控能力已形成冻结仿真控制基线。
- 当前 100Hz 仿真平衡已经可以稳住，先作为阶段性基线冻结。
- 当前参数不视为实机最终参数，后续以 STM32 接入后的真实 IMU、编码器、电机响应和通信延迟重新调参。
- 当前 STM32 与 ROS 第一版通信边界已记录：使用串口通信，两侧手动解包；当前硬件主线按 `200Hz` 上报状态并按 `200Hz` 口径消费 `/robot_state`，STM 执行六电机力矩指令。
- 当前正式通信节点 V1 代码已接入仓库：ROS 侧 bridge 不再是占位节点，`RcStatus` 已新增 `estop_active`，默认 `RC channel 7` 低值端为急停，并由 bridge 直接门控下行 `enable/estop` 命令帧。
- 当前控制层接入 STM 的第一版代码已接入仓库：`wheel_leg_controller` 支持阶段开关，`hw.launch.py` 默认加载硬件保守参数，`sim.launch.py` 默认加载仿真全功能参数，硬件状态装配已从 bridge 节点拆出并加单元测试。
- `2026-06-27` 已将 `control_hw.yaml` 切换到 `expected_dt_sec = 0.005`、`accepted_dt_tolerance_sec = 0.002`，用于接受 `200Hz` 硬件状态样本。
- `2026-07-04` 硬件控制门控曾收口为“腿长 PID + VMC + 髋/膝输出”的单独验证模式，用于完成腿长控制阶段。
- `2026-07-07` 已完成 LQR + VMC 悬空方向复核：状态顺序保持 `[phi, phi_rate, distance, velocity, pitch, pitch_rate]`；修正 LQR 两路输出语义，第一路取反作为 VMC 腿摆杆虚拟力矩，第二路作为轮端输出。`command_enable=false` 下验证 `phi_c < phi_target` 时 hip 为较大正力矩，`length_c > length_target` 时 knee 为较大负力矩。
- `2026-07-07` LQR 调参收口：髋部输出行 `phi` / `phi_rate` 增益乘 `0.6`，新增 `phi_rate_damping_kd=-0.2` 只作用髋部虚拟力矩，不进入轮端力矩。
- `2026-07-07` 当前硬件默认配置已进入 LQR 阶段：VMC、LQR、腿长 PID、轮端输出、髋/膝输出均默认开启；heading、anti-split、roll compensation 仍默认关闭。

## 7. 当前阻塞或待确认问题

### 7.1 100Hz 仿真阶段

- 100Hz 控制频率下的 MuJoCo 仿真已经可以稳住。
- 该阶段先冻结为仿真可运行基线，不继续只在仿真中深调参数。
- 当前参数不视为实机最终参数；硬件接入后需要根据真实日志重新调整。

### 7.2 STM32 通信与状态上报

- STM32 状态上报 `200Hz` 已验证通过；ROS 硬件控制主线也已切到 `200Hz` 口径。
- `2026-06-25` 已完成 Raspberry Pi UART4 与 STM32 USART2 的首轮 5 秒双向联调：ROS 侧可稳定解出 `type=0x81` 状态帧，ROS 下行发送无 `write_errors`/`partial_writes`，复测窗口内 STM32 新增 `crc_errors`、`length_errors`、`sync_losses`、`uart_errors` 均为 `0`。
- 首次失败原因已确认是未共地；补上 `Raspberry Pi GND -- STM32 GND` 后通信恢复正常。
- `2026-06-25` 随后又定位到正式状态帧发送异常的根因收敛为：`USART2` 上持续 `HAL_UART_Receive_IT(..., 1)` 与阻塞式 `HAL_UART_Transmit()` 组合会导致发送侧稳定 `HAL_TIMEOUT`；加入“发送前 `HAL_UART_AbortReceive_IT()`、发送后重启接收”的联调绕过后，STM32 上行 `tx_err` 清零且状态帧恢复稳定发送。
- `2026-06-26` 继续实测后确认，当前把状态发送挂入 `Data_Task` 后单轮循环耗时约 `5.58ms`，已经超过 `5ms` 周期预算；当前主优化方向固定为两项：`USART2` 状态帧改为 DMA/中断非阻塞发送，以及 `JY901S` 从 `0x34~0x3F` 连续寄存器块读替代 9 次分散软件 I2C 读取。
- 当前剩余卡点已转移到 ROS/树莓派到 STM32 的下行命令接收链路；此时 `tx` 可持续增长，但 `rx_ok`、`last_rx` 仍可能保持为 `0`，需继续核对串口设备名、接线、发送时机与接收统计。
- 后续仍建议补一轮更长时间窗口测试，继续观察 `rx_seq_gaps` 是否偶发增长。
- 待确认 STM32 上传的编码器、IMU、电机反馈可以稳定映射到 ROS2 状态接口。
- 待确认时间戳和 `dt` 口径在实机整链下稳定围绕 `0.005s`。
- 待完成正式状态帧新 payload 与 ROS bridge 的上板联调，确认字段顺序、单位和字节序与当前代码一致。

### 7.3 命令下发与安全保护

- 待确认 `/joint_command` 下发到 STM32 后，各电机动作方向、单位、限幅和斜率限制正确。
- 待确认通信异常、遥控 failsafe 或控制异常时可以进入安全状态。
- 待确认初次调试时可以使用悬空、低力矩、单关节方式逐项验证。
- 待验证 `RC ch7 -> /rc/status.estop_active -> bridge estop=1 -> STM32 整车失能` 整链行为。
- `2026-06-26` 已在 `wheel_leg_stm32_bridge` 增加 ROS 侧本地限位保护：当 hip 世界角或 knee 相对角到达文档记录的机械限位，且该关节实际回传力矩绝对值大于阈值时，bridge 锁存 `local_estop` 并持续向 STM32 下发 `estop`。
- `2026-07-07` 为便于悬空观察内部力矩，`hw.launch.py` 默认将 `joint_limit_protection.effort_threshold_nm` 设为 `0.0`，即关闭 bridge 本地限位保护。

### 7.4 传感器方向与单位

- 待确认 pitch / pitch_rate 正方向与仿真一致。
- 当前角度解算使用角速度积分；实机观测为向左转动时角度为正向增加，向右转动时角度为反向减小，后续需要与 ROS2 / LQR 使用的姿态方向统一。
- 待确认左右腿 `phi` / `phi_rate` 正方向与 LQR 状态定义一致。
- 当前腿部世界角约定为右侧水平轴 `0 deg`、顺时针为正、竖直向下 `90 deg`、竖直向上 `270 deg`；STM32 上报到 ROS bridge 的髋关节和小腿角已经是世界坐标系 absolute 角，bridge 不再叠加仿真 offset。
- `2026-06-27` 已修正仿真侧和 STM32 bridge 的 `phi/leg_length` 解算：使用 `delta = hip_absolute - calf_absolute`、`knee_angle = pi - delta`、`lower_link_absolute = hip_absolute - pi + knee_angle`，再由大小腿三角形求腿对角边和世界系 `phi`。
- `2026-06-27` 已记录并接入实物侧目标限幅：`target_leg_length_min/max = 0.15/0.32 m`，`target_phi_min/max = 30/150 deg`。
- VMC 髋/膝力矩映射已复核：按二连杆世界角重算腿长与腿角，再映射虚拟腿长力/腿摆杆力矩到 hip/knee。
- 当前机械范围记录：hip 世界角活动范围为 `75 ~ 200 deg`；knee 自身相对角范围不包含 hip 转动，当前限位测试范围为 `-140 ~ -70 deg`；固件已加 `knee_limit_flag` 用于到达限位监测。
- 待确认轮子前进方向与 `base_link.velocity` 正方向一致。
- 待确认 `/robot_state` 中 `hip_absolute`、`calf_absolute` 与实物世界角一致。

### 7.5 实机调参入口

- 实机闭环初期优先观察 `pitch`、`pitch_rate`、`phi`、`phi_rate`、`base_velocity`、轮端力矩和髋关节力矩。
- 当前进度口径：腿长控制阶段已完成，LQR + VMC 悬空输出方向已复核，本轮 LQR 调参已收口；下一步主看 `pitch/pitch_rate/base_velocity`、轮端方向和轻触地稳定性。
- 轻触地前必须确认当前 launch 仍为 `command_enable=false`，先观察 `/joint_command`；准备实际输出时再显式改为 `command_enable=true` 并使用低限幅。
- 若出现 pitch 高频震荡，优先检查 IMU 方向、gyro 滤波、`pitch_rate` 增益和执行器斜率限制。
- 若出现缓慢前后跑偏，优先检查 `target_phi`、`target_pitch`、速度方向和距离积分。
- 若出现单侧压低，优先检查左右腿角度、roll、VMC 映射和左右电机方向。

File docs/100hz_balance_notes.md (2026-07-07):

# `kActuatorOutputLPFRC = 0.02`轮腿平衡控制从 500Hz 调整到 100Hz 的修改记录

本文档记录本工程从 500Hz 控制周期切换到 100Hz 控制周期后，为了让轮腿机器人重新保持站立平衡所做的关键修改。

最终目标不是锁住浮动基座自由度，而是在保持 `freejoint` 的前提下，让控制器、传感器估计、滤波器、LQR 增益和 MuJoCo 仿真步长都匹配 `0.01s` 的控制周期。

## 1. 背景

原始控制频率：

```text
500Hz, dt = 0.002s
```

目标控制频率：

```text
100Hz, dt = 0.01s
```

控制周期从 `0.002s` 变成 `0.01s` 后，采样周期变为原来的 5 倍。这个变化会直接影响：

- PID 的积分和微分计算
- 速度估计
- 低通滤波器截止频率
- LQR 离散化模型
- pitch / pitch_rate 反馈的相位裕度
- MuJoCo 接触求解稳定性
- 执行器输出变化速度

因此，不能只把主循环改成每 `0.01s` 执行一次。所有和时间有关的控制器、滤波器、传感器估计都需要一起修改。

## 2. 主要失稳现象

降到 100Hz 后出现过几类典型失稳现象：

1. 一落地直接发散。
2. 站立约 `0.5s` 后开始剧烈震荡。
3. 下盘能稳住，但浮动基座出现高频 pitch 抖动，然后发散。
4. 加入转向环、抗劈叉环后重新失衡。
5. 删除附加环后，单独 LQR + VMC 仍然可能因为 pitch 反馈过激而震荡。

最终判断：主要失稳来源不是自由度被放开本身，而是 100Hz 下 pitch / pitch_rate / velocity 等反馈项的离散延迟、速度噪声和滤波相位滞后共同作用，使 LQR 对浮动基座施加了过激力矩。

## 3. 控制周期修改

相关文件：

```text
simulate/wheel_leg/wheel_leg_hooks.cc
```

当前控制周期由 MuJoCo timestep 和控制降采样共同决定：

```cpp
constexpr int kControlDecimation = 1;
```

控制器实际 dt：

```cpp
const float control_dt =
    static_cast<float>(m->opt.timestep * kControlDecimation);
```

因为当前 MuJoCo timestep 已经是 `0.01s`，所以：

```text
control_dt = 0.01 * 1 = 0.01s
```

这表示控制器每个仿真步都运行一次，但由于仿真步长本身就是 `0.01s`，控制频率就是 100Hz。

## 4. PID 时间步长修改

相关文件：

```text
simulate/tools/pid.cc
simulate/tools/pid.h
simulate/wheel_leg/wheel_leg_hooks.cc
```

PID 不能继续使用固定的 `0.002s`。积分项和微分项都必须使用实际控制周期。

当前 PID 默认周期改成：

```cpp
float PIDCalculate(PIDInstance *pid, float measure, float ref) {
    return PIDCalculateWithDt(pid, measure, ref, 0.01f);
}
```

同时新增或使用带 dt 的接口：

```cpp
float PIDCalculateWithDt(PIDInstance *pid, float measure, float ref, float dt);
```

控制器中调用：

```cpp
PIDCalculateWithDt(&leglen_pid_l, left_leg.leg_length,
                   target_leg_length, control_dt);
```

这样积分计算按 `error * dt` 累积，微分计算按 `delta / dt` 计算，不会再隐含 500Hz 的时间尺度。

## 5. 低通滤波器从固定 alpha 改为 RC 形式

相关文件：

```text
simulate/tools/sensor.cc
```

原来类似：

```cpp
constexpr double kPhiRateLowPassAlpha = 0.95;
```

这类固定 alpha 和采样周期强相关。同样的 `alpha = 0.95`，在 `0.002s` 和 `0.01s` 下对应的物理截止频率完全不同。

现在改为 RC 形式：

```cpp
double LowPass(double previous, double current, double rc, double dt) {
  if (dt <= 0.0 || rc <= 0.0) {
    return current;
  }
  const double alpha = rc / (rc + dt);
  return alpha * previous + (1.0 - alpha) * current;
}
```

当前使用的 RC 参数：

```cpp
constexpr double kPhiRateLowPassRC = 0.02333333333333333;
constexpr double kBaseVelocityLowPassRC = 0.03;
constexpr double kGyroLowPassRC = 0.02;
```

在 `dt = 0.01s` 时，对应的 alpha 约为：

```text
phi_rate alpha = 0.02333 / (0.02333 + 0.01) = 0.70
base velocity alpha = 0.03 / (0.03 + 0.01) = 0.75
gyro alpha = 0.02 / (0.02 + 0.01) = 0.667
```

这样做的好处是：之后如果控制周期再次变化，只要继续使用实际 `dt`，滤波器仍然有明确的物理时间常数。

## 6. 传感器速度估计修改

相关文件：

```text
simulate/tools/sensor.cc
simulate/tools/sensor.h
```

100Hz 下速度估计比 500Hz 更敏感。特别是 LQR 状态中的：

- `phi_rate`
- `base_link.velocity`
- `base_link.pitch_rate`

这些量如果噪声大、延迟大或者方向错，会直接通过 LQR 反馈放大成力矩震荡。

这里要区分“角度状态”和“速度状态”。在当前仿真里，`phi` 和 `pitch` 角度本身通常不是最主要的高频噪声来源；真正容易把系统推到震荡的是：

```text
phi_rate
pitch_rate
base_link.velocity
```

也就是说，主要问题不是 LQR 看到了很吵的 `phi` 或 `pitch`，而是 100Hz 下由编码器/几何计算得到的腿角速度、由 gyro 得到的 pitch 角速度、以及基座前向速度更容易带噪声和相位滞后。LQR 对这些速度项的反馈一旦过强，就会把速度噪声放大成轮子和髋关节力矩抖动。

传感器部分是这次能稳住的关键之一。因为 LQR 本身只看状态量，它并不知道状态量是真实运动，还是由采样周期、差分噪声、IMU 噪声、坐标方向错误带来的假信号。500Hz 时这些问题可能被高频采样掩盖；到了 100Hz，每个错误状态会保持 `0.01s`，更容易把基座 pitch 推进震荡。

### 6.1 phi_rate

`phi_rate` 不再依赖简单差分，而是通过腿部几何和关节速度解析计算，再做低通滤波。

滤波函数：

```cpp
FilterPhiRate(&sensor_data.left_leg.kinematics,
              &filtered_left_phi_rate,
              &has_previous_left_phi_rate,
              dt);
```

这里要避免的错误是：

```text
phi_rate = (phi_now - phi_last) / dt
```

这种差分在 100Hz 下会明显放大量化噪声和角度抖动。腿部角度 `phi` 由多个关节角组合得到，任何一个关节角的小抖动都会被 `/ 0.01` 放大成速度抖动，再进入 LQR。

当前做法是先根据腿端几何变化计算角速度：

```text
phi_rate = (x * y_velocity - y * x_velocity) / (x^2 + y^2)
```

这个形式本质上是二维向量角度变化率，比直接对 `phi` 做差分更平滑，也更适合 100Hz。

随后再经过：

```cpp
constexpr double kPhiRateLowPassRC = 0.02333333333333333;
```

在 `dt = 0.01s` 下：

```text
alpha = 0.02333 / (0.02333 + 0.01) ~= 0.70
```

也就是当前速度估计保留约 70% 的上一时刻结果，混入约 30% 的新观测。这样可以压住速度噪声，同时延迟还不至于太大。

### 6.2 base forward velocity

基座前向速度优先读取平面关节速度；如果当前模型使用 `freejoint`，则用浮动基座在世界系下的速度投影到 yaw 方向：

```cpp
const double forward_x = std::cos(yaw);
const double forward_y = std::sin(yaw);
return d->qvel[0] * forward_x + d->qvel[1] * forward_y;
```

然后对前向速度做 RC 低通：

```cpp
filtered_base_forward_velocity =
    LowPass(filtered_base_forward_velocity,
            raw_base_forward_velocity,
            kBaseVelocityLowPassRC,
            dt);
```

距离状态不再从位置传感器直接读，而是用滤波后的速度积分：

```cpp
base_forward_distance += filtered_base_forward_velocity * dt;
```

这里有两个重点。

第一，`freejoint` 模型下基座的 `qvel[0]` 和 `qvel[1]` 是世界系平动速度，不是机器人机体系前向速度。因此要根据 yaw 做投影：

```text
base_forward_velocity = vx_world * cos(yaw) + vy_world * sin(yaw)
```

否则机器人转过一定角度后，LQR 看到的前进速度方向会错，轮子力矩会补偿到错误方向。

第二，距离状态用速度积分而不是直接依赖某个仿真位置关节，是为了让 `distance` 和 `velocity` 来自同一套前向定义。否则可能出现：

```text
distance 是世界 x
velocity 是机体前向
```

这会让 LQR 的位置和速度状态不一致。100Hz 下这种不一致也会表现成慢慢积累的力矩偏置。

当前速度低通：

```cpp
constexpr double kBaseVelocityLowPassRC = 0.03;
```

在 `dt = 0.01s` 下：

```text
alpha = 0.03 / (0.03 + 0.01) = 0.75
```

这比 `phi_rate` 更稳一点，因为 base velocity 直接影响轮子力矩。如果这个量噪声太大，轮子会前后快速抽动，再通过地面接触激发 pitch。

### 6.3 gyro / pitch_rate

`pitch_rate` 来自 `base_gyro[1]`，并经过 RC 低通：

```cpp
filtered_base_gyro[i] =
    LowPass(filtered_base_gyro[i], base_gyro[i], kGyroLowPassRC, dt);
```

这是 100Hz 能稳定的重要点之一。因为 pitch_rate 是 LQR 中最容易激发高频震荡的状态之一。

当前陀螺仪低通：

```cpp
constexpr double kGyroLowPassRC = 0.02;
```

在 `dt = 0.01s` 下：

```text
alpha = 0.02 / (0.02 + 0.01) ~= 0.667
```

`pitch_rate` 的处理比 `base_velocity` 稍微快一些，因为姿态角速度需要及时反映基座倾倒趋势。但它又不能完全不过滤，因为 LQR 对 `pitch_rate` 很敏感，未滤波的 gyro 噪声会直接变成高频轮子力矩和髋关节力矩。

这次最终还在 LQR 里把 `pitch_rate` 反馈缩放到 `0.35`，原因也是一样：100Hz 下 `pitch_rate` 同时存在测量噪声和相位滞后，高增益会让基座 pitch 进入自激振荡。

### 6.4 dt 必须从控制器传入传感器

当前传感器接口支持显式传入 dt：

```cpp
RobotSensorData AssembleSensorData(const mjModel* m, const mjData* d,
                                   double dt);
```

控制器中使用：

```cpp
const RobotSensorData sensor_data = AssembleSensorData(m, d, control_dt);
```

这个细节很重要。滤波器、速度积分、距离积分都必须使用控制器实际周期，而不是假设固定频率。

如果以后改成：

```text
仿真步长 0.002s
控制器每 5 步运行一次
控制周期 0.01s
```

那么传感器给控制器用的数据也应该按 `control_dt = 0.01s` 更新。否则会出现控制器 100Hz，传感器滤波却按 500Hz 的错配。

### 6.5 传感器状态初始化

传感器滤波中使用了静态变量保存上一时刻状态：

```cpp
static bool has_previous_left_phi_rate = false;
static bool has_previous_right_phi_rate = false;
static double filtered_left_phi_rate = 0.0;
static double filtered_right_phi_rate = 0.0;
static bool has_previous_base_velocity = false;
static bool has_previous_gyro = false;
static double filtered_base_forward_velocity = 0.0;
static std::array<double, 3> filtered_base_gyro = {0.0, 0.0, 0.0};
static double base_forward_distance = 0.0;
```

第一次读取时不直接滤波，而是用当前测量初始化：

```text
filtered = raw
has_previous = true
```

这样可以避免启动瞬间从 0 慢慢滤到真实值，导致控制器在前几帧看到假的速度或假的 pitch_rate。

上硬件时也要注意类似问题：IMU 和编码器滤波器最好在控制使能前先初始化到当前测量值，而不是上电默认 0。

### 6.6 传感器方向和单位检查

100Hz 稳定对传感器方向非常敏感，上硬件前必须确认：

```text
pitch 单位: rad
pitch_rate 单位: rad/s
phi 单位: rad
phi_rate 单位: rad/s
base velocity 单位: m/s
distance 单位: m
```

还要确认正方向：

```text
机器人向前倒时，pitch 符号是否和仿真一致
机器人向前倒得更快时，pitch_rate 符号是否和仿真一致
轮子向前滚动时，base velocity 是否为正
腿部 phi 增大方向是否和 LQR_K.m 建模一致
左右腿关节角正方向是否和 VMC 一致
```

如果某个速度方向反了，100Hz 下通常不会表现为温和偏差，而是会直接形成正反馈。例如 pitch_rate 符号反了，LQR 本来想阻尼基座俯仰，结果会变成主动推倒基座。

### 6.7 传感器和 LQR 状态的一一对应

当前 LQR 状态顺序是：

```text
x[0] = phi
x[1] = phi_rate
x[2] = distance
x[3] = velocity
x[4] = pitch
x[5] = pitch_rate
```

注意这里的 `phi` 是腿摆杆角，对应 MATLAB 推导中的 `theta`；`pitch`
是机体倾角，对应 MATLAB 推导中的 `phi/varphi`。不要按符号名直觉把
两者换位。2026-07-07 实机复核中曾误判为状态顺序错，实际 C++ 原状态
顺序与 MATLAB 模型一致。

LQR 输出通道也必须和 MATLAB 模型语义对应。当前 `LQR_K.m` 的两行输出
不能简单按旧 C++ 的 `wheel_torque, hip_torque` 理解；实机复核确认腿摆杆角
恢复量主要在第一行输出中。当前控制中采用：

```text
wheel_torque = lqr_output[1]
hip_virtual_torque_for_vmc = -lqr_output[0]
```

这次问题的直接现象是：`phi_c < phi_target` 时，旧映射下 hip 只有
`0.03 ~ 0.05 Nm`，而较大的恢复量跑到了 wheel 输出；修正后同一工况下
hip 输出约 `+1.9 ~ +2.9 Nm`，knee 在 `length_c > length_target` 时保持负力矩。

传感器输出必须严格对应这个顺序。尤其要避免以下错配：

```text
把 roll_rate 当 pitch_rate
把世界系 x 速度当机体前向速度
把角度单位 deg 传给期望 rad 的 LQR
左右腿 phi 定义不一致
distance 和 velocity 使用不同坐标系
```

这类错误在 500Hz 下可能还能短时间看起来能站住，但在 100Hz 下通常会更快暴露为 pitch 高频震荡。

### 6.8 上硬件时建议的传感器处理顺序

硬件上建议按下面顺序组织传感器数据：

1. 读取原始编码器、IMU、轮速。
2. 做零点校准和方向修正。
3. 统一单位到 rad、rad/s、m/s。
4. 用当前控制周期 `dt = 0.01s` 更新滤波器。
5. 计算腿部几何量 `phi`、`leg_length`。
6. 用关节速度解析计算 `phi_rate`。
7. 将 IMU 世界/机体系数据转换到控制器定义的坐标。
8. 得到 LQR 状态向量。
9. 再调用 LQR 和 VMC。

不要把滤波放在方向修正之前。方向修正、零点修正、单位换算应该先完成，再滤波。否则滤波器内部状态会混入错误坐标系下的历史数据。

### 6.9 传感器部分的最终原则

从 500Hz 到 100Hz，传感器部分的核心原则是：

```text
不用粗糙差分制造速度；
不用固定 alpha 隐含采样周期；
不用世界系速度冒充机体前向速度；
不用未滤波 pitch_rate 直接进 LQR；
不用和控制周期不一致的 dt 更新滤波器。
```

当前稳定版本能够站住，传感器侧主要依赖这几件事：

```text
phi_rate 解析计算 + RC 低通
base velocity 按 yaw 投影 + RC 低通
distance 由滤波后的前向速度积分
gyro / pitch_rate RC 低通
所有滤波器使用 control_dt = 0.01s
传感器状态和 LQR 状态顺序严格对应
```

## 7. MuJoCo timestep 和接触参数修改

相关文件：

```text
model/scence.xml
model/wheel_leg.xml
```

仿真步长改为：

```xml
<option timestep="0.01" gravity="0 0 -9.81" integrator="implicitfast"
        iterations="100" tolerance="1e-8" density="1.225" viscosity="1.8e-5" />
```

地面接触参数调整为偏软：

```xml
friction="0.8 0.02 0.001"
solref="0.04 1"
solimp="0.9 0.95 0.001"
```

默认关节也加入了适度阻尼和转子惯量：

```xml
<joint damping="0.03" armature="0.003"/>
```

这些修改的作用是降低 `0.01s` 大步长下接触瞬间的数值刚性，避免落地时把高频冲击直接注入基座 pitch。

## 8. 保持自由基座，不锁自由度

相关文件：

```text
model/wheel_leg.xml
```

当前基座保持自由浮动：

```xml
<body name="base_body" pos="0 0 0.28">
  <freejoint/>
</body>
```

曾经短暂尝试过限制自由度来判断问题来源，但最终稳定版本没有锁自由度。这样更接近真实硬件，因为真实机器人不会被仿真器额外约束 roll / pitch / yaw 或平移自由度。

需要注意：`freejoint` 下能稳住，才说明控制器本身对浮动基座是有效的；锁自由度得到的稳定结果不能直接代表真实硬件可行。

## 9. LQR 增益重新同步到 100Hz 版本

相关文件：

```text
simulate/matlab_function/LQR_K.m
simulate/tools/lqr_k.cc
```

LQR 增益必须按新的离散周期重新生成。500Hz 下的离散 LQR 直接拿到 100Hz 用，通常会出现相位裕度不足、速度反馈过激、pitch_rate 抖动放大等问题。

当前 `lqr_k.cc` 已按 `LQR_K.m` 的 100Hz 结果同步，并保持 MATLAB reshape 的列主序映射：

```cpp
return {{
    {{mt1, mt3, mt5, mt7, mt9, mt11}},
    {{mt2, mt4, mt6, mt8, mt10, mt12}},
}};
```

其中 LQR 状态顺序是：

```cpp
LqrVector BuildLqrStates(const LegState& leg,
                         const RobotSensorData& sensor_data) {
  return {{
      leg.kinematics.phi,
      leg.kinematics.phi_rate,
      sensor_data.base_link.distance,
      sensor_data.base_link.velocity,
      sensor_data.base_link.pitch,
      sensor_data.base_link.pitch_rate,
  }};
}
```

目标状态：

```cpp
return {{
    targets.target_phi,
    0.0,
    targets.target_distance,
    targets.target_velocity,
    0.0,
    0.0,
}};
```

## 10. 对 pitch 相关 LQR 反馈降幅

相关文件：

```text
simulate/tools/lqr_k.cc
```

最终稳定的关键之一，是降低 100Hz 下最容易激发基座高频震荡的 LQR 反馈项：

```cpp
constexpr double kPhiRateFeedbackScale = 0.6;
constexpr double kVelocityFeedbackScale = 1.0;
constexpr double kPitchFeedbackScale = 0.7;
constexpr double kPitchRateFeedbackScale = 0.35;
```

实际返回增益时：

```cpp
return {{
    {{mt1,
      mt3 * kPhiRateFeedbackScale,
      mt5,
      mt7 * kVelocityFeedbackScale,
      mt9 * kPitchFeedbackScale,
      mt11 * kPitchRateFeedbackScale}},
    {{mt2,
      mt4 * kPhiRateFeedbackScale,
      mt6,
      mt8 * kVelocityFeedbackScale,
      mt10 * kPitchFeedbackScale,
      mt12 * kPitchRateFeedbackScale}},
}};
```

含义：

- `phi_rate` 降到 60%
- `velocity` 保持 100%
- `pitch` 降到 70%
- `pitch_rate` 降到 35%

其中 `pitch_rate` 降幅最大，因为它在 100Hz 下最容易把陀螺仪噪声、滤波延迟和离散误差放大成高频力矩。

这不是额外增加一个姿态环，而是在现有 LQR 内部对敏感状态做保守化处理。

调试过程中曾经把 `velocity` 反馈降到 `0.5`，这样有利于先压住 pitch 高频震荡，但副作用是速度阻尼不足：机器人会先往前跑，距离误差变大后再被拉回，回到原点时速度仍然不为 0，形成低频来回摆。后续测试发现 `kVelocityFeedbackScale = 1.0` 更合适，说明在传感器滤波和 pitch_rate 增益已经压住以后，速度反馈需要恢复足够的阻尼能力。

## 11. 暂时只保留 LQR + VMC

相关文件：

```text
simulate/wheel_leg/wheel_leg_hooks.cc
```

当前站立稳定版本只保留：

- 腿长 PID
- LQR
- VMC 力矩映射
- 执行器输出限幅、低通和斜率限制

暂时不启用：

- 转向环
- 抗劈叉环
- 额外 roll / yaw 弱阻尼环

原因是附加环在 100Hz 下会带来额外相位滞后和耦合。如果基础 LQR + VMC 刚刚稳定，直接叠加转向环或抗劈叉环，很容易重新把系统推到失稳边缘。

建议后续加环顺序：

1. 先确认 LQR + VMC 在不同初始姿态下都能站稳。
2. 再加非常小增益的 yaw / 转向环。
3. 最后再加抗劈叉或左右腿同步环。
4. 每加一个环都记录 pitch、pitch_rate、wheel torque、hip torque。

## 12. 执行器输出平滑

相关文件：

```text
simulate/wheel_leg/wheel_leg_hooks.cc
```

当前执行器输出有力矩限幅、低通和斜率限制：

```cpp
constexpr double kJointTorqueLimit = 120.0;
constexpr double kWheelTorqueLimit = 80.0;
constexpr double kActuatorOutputLPFRC = 0.02;
constexpr double kActuatorOutputRateLimit = 600.0;
```

输出处理：

```cpp
const double alpha =
    kActuatorOutputLPFRC / (kActuatorOutputLPFRC + std::max(dt, 1e-6));
double output = alpha * *filtered_output + (1.0 - alpha) * clipped_output;

const double max_delta = kActuatorOutputRateLimit * std::max(dt, 0.0);
output = std::clamp(output, *filtered_output - max_delta,
                    *filtered_output + max_delta);
```

在 `dt = 0.01s` 下，最大单步变化量：

```text
600 * 0.01 = 6 N*m per step
```

这可以避免 LQR 输出突变直接打到关节和轮子上，降低 pitch 高频震荡风险。

## 13. 为什么 500Hz 稳，100Hz 初始不稳

500Hz 下：

- 采样周期短
- 速度估计延迟小
- 微分项更新快
- LQR 离散近似更接近连续系统
- 同样的力矩变化在每个周期内作用时间短

100Hz 下：

- 每次控制输出保持 `0.01s`
- 速度和角速度估计更粗
- 滤波器相位滞后更明显
- pitch_rate 噪声更容易被 LQR 放大
- 接触冲击在大步长下更容易激发数值震荡
- 原本在 500Hz 下还能接受的高增益，在 100Hz 下可能变成过激反馈

因此，100Hz 稳定不是简单降低频率，而是需要降低高敏感反馈项、重新配置滤波器，并让传感器估计和控制 dt 一致。

## 14. 与真实硬件的对应关系

当前稳定版本更接近真实硬件的地方：

- 保留 `freejoint`，没有用仿真约束强行稳定基座。
- 控制周期使用 `0.01s`，对应硬件 100Hz 控制循环。
- PID、滤波器、速度积分都显式使用实际 dt。
- 执行器输出有斜率限制，接近真实电机无法无限快改变力矩的事实。
- pitch_rate 经过滤波，接近真实 IMU 需要滤波后使用的情况。

仍然需要注意的差异：

- MuJoCo 中的接触参数和真实轮胎/地面不完全一致。
- 仿真里电机力矩响应仍然比真实硬件理想。
- 真实 IMU 会有零偏、延迟、安装误差和噪声。
- 真实编码器速度估计可能比仿真更脏。
- 电机驱动器本身可能还有电流环带宽、限流、死区和通信延迟。

因此，上硬件时建议先保持当前保守增益，不要一开始就恢复高 pitch_rate 增益。

## 15. 上硬件前建议检查

上硬件前建议重点确认：

1. 控制循环实际周期是否稳定在 `0.01s`。
2. IMU 的 pitch 正方向是否和仿真一致。
3. gyro pitch_rate 正方向是否和 LQR 状态定义一致。
4. 轮子速度正方向是否和 `base_link.velocity` 定义一致。
5. 髋关节、膝关节角度零点是否和仿真 offset 对齐。
6. VMC 输出到电机的力矩方向是否正确。
7. 电机最大力矩是否低于仿真中的限幅。
8. 电机力矩斜率是否不要比仿真中 `600 N*m/s` 更激进。
9. 初次上电时腿长目标和实际腿长不要差太多。
10. 先悬空验证关节方向，再轻触地验证支撑力方向，最后再尝试站立。

## 16. 调试时建议记录的变量

如果后续再次出现 pitch 震荡，建议优先打印或记录：

```text
time
pitch
pitch_rate
phi_left
phi_rate_left
phi_right
phi_rate_right
base_velocity
base_distance
left_wheel_torque
right_wheel_torque
left_hip_torque
right_hip_torque
left_leg_length
right_leg_length
```

判断方法：

- 如果 `pitch_rate` 先出现尖峰，再出现大力矩，通常是 gyro 噪声或 pitch_rate 增益过高。
- 如果 `base_velocity` 符号和机器人实际运动方向相反，可能是速度方向定义错。
- 如果 `wheel_torque` 在正负限幅间跳变，通常是 LQR 速度或 pitch_rate 反馈过激。
- 如果 `hip_torque` 先发散，可能是 VMC 力矩映射、腿角方向或 pitch 反馈耦合问题。
- 如果落地瞬间直接炸，优先看接触参数、腿长支撑力和执行器斜率限制。

## 17. 当前稳定版本总结

当前能在 100Hz 保持站立平衡的关键组合是：

```text
MuJoCo timestep = 0.01s
Control decimation = 1
Control dt = 0.01s
Base joint = freejoint
Controller = leg length PID + LQR + VMC
Sensor filter = RC filter with actual dt
LQR gain = 100Hz version from LQR_K.m
phi_rate / pitch / pitch_rate feedback = conservative scaling
velocity feedback = 1.0 after stability is recovered
Actuator output = torque limit + LPF + rate limit
Extra yaw / anti-split loops = disabled
```

一句话总结：

```text
从 500Hz 改到 100Hz 后，稳定性的关键不是锁自由度，而是让控制器、传感器速度估计、滤波器、LQR 增益和执行器输出都按 0.01s 的真实控制周期重新匹配，并降低 pitch_rate 这类高敏感反馈项。
```

## 18. 阶段冻结状态

当前 100Hz 控制频率下的仿真站立平衡已经可以稳住，本阶段先作为仿真可运行基线冻结。

冻结口径：

- 当前目标不是继续在 MuJoCo 中把所有参数调到最终形态。
- 当前参数只能证明 100Hz 控制链在仿真中具备基础稳定性。
- 真实硬件接入后，IMU 零偏、编码器速度噪声、电机响应、通信延迟、地面接触和结构装配误差都会改变最优参数。
- 后续参数调整应以硬件接入后的实测日志为准，尤其是 `pitch_rate`、`phi_rate`、`base_velocity`、轮端力矩和髋关节力矩。

因此，本阶段暂不继续扩大 100Hz 仿真调参范围。下一阶段转入 STM32 / 实机硬件接入，先打通真实状态上报、命令下发、安全停机和方向/单位校验，再在硬件闭环上重新小步调

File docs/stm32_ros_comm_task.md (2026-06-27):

# STM32 与 ROS 通信内容任务

## 1. 任务目标

本任务用于固定 STM32 层与 ROS 层第一版通信内容，为后续实现 `wheel_leg_stm32_bridge` 和 STM32 协议任务提供依据。

第一版边界：

- STM32 只上传原始或近原始硬件数据。
- ROS 侧完成全部控制计算。
- ROS 下发六电机力矩指令。
- STM32 负责协议收发、单位映射、限幅、斜率限制、安全停机和电机执行。

本任务不把平衡控制下放到 STM32，也不在本阶段引入完整 `ros2_control`。

## 2. 分层边界

通信主链保持为：

```text
STM32 firmware
  ↑↓
UART protocol
  ↑↓
wheel_leg_stm32_bridge
  ↑↓
/robot_state and /joint_command
  ↑↓
wheel_leg_controller
```

约束：

- `wheel_leg_control` 不解析 STM32 二进制协议。
- `wheel_leg_stm32_bridge` 负责协议编解码和 ROS 消息映射。
- `firmware/stm32` 负责实时采样、电机执行和底层安全保护。
- 上层控制器不感知底层是 MuJoCo 还是 STM32。

## 3. 通信周期与链路

第一版控制闭环最初按 `100Hz` 规划，但随着 STM32 上行稳定到 `200Hz`，当前硬件主线已经转为 `200Hz` 控制口径：

- ROS 侧控制器当前按 `200Hz` 口径消费状态并发布 `/joint_command`。
- ROS 到 STM32 的命令帧按最新 `/joint_command` 下发。
- STM32 必须基于命令超时进入安全输出，不依赖 ROS 主动发送停机帧。
- STM32 以 `200Hz` 频率发送状态帧，ROS 侧按每帧驱动 `/robot_state`。
- 当前实测 STM32 读完一次传感器约在 `3ms` 以内，因此优先测试 `200Hz` 状态上报。
- 最终状态上报频率由 STM32 传感器读取耗时、串口带宽、解包开销、丢包率和控制链稳定性共同决定。

链路明确使用 UART/串口通信。当前 `USART2` 压测入口默认配置为 `921600 8N1`；若线缆、地线、树莓派串口和 STM32 侧错误计数都稳定，再继续测试 `1000000` 或 `2000000`。

由于串口是字节流，不提供天然消息边界，STM32 侧和 ROS bridge 侧都必须手动解包：

- 两侧都维护接收缓冲区和状态机。
- 通过帧头进行帧同步。
- 读取长度字段后等待完整 payload。
- 对帧类型、长度和 CRC 进行校验。
- 校验通过后再解析 payload 并更新状态或命令。
- 校验失败时丢弃坏帧并重新寻找下一帧头。

## 4. STM32 到 ROS 状态上报

状态帧至少包含以下内容。

### 4.1 时间与序号

- `seq`：状态帧递增序号，用于检测丢包和乱序。
- `stm_tick_ms` 或等价周期计数：用于估算 STM32 侧采样周期和 ROS 侧 `dt`。

### 4.2 IMU 数据

STM32 上传原始或近原始 IMU 数据，ROS 侧再映射到控制语义：

- 姿态角或四元数。
- `gyro_x`、`gyro_y`、`gyro_z`，单位最终进入 ROS 时为 `rad/s`。
- `acc_x`、`acc_y`、`acc_z`，单位最终进入 ROS 时为 `m/s^2`。

后续实现时需要记录 IMU 坐标轴、正方向和滤波口径，保证 `/robot_state` 中 `body_pitch`、`body_pitch_rate` 与仿真和 LQR 状态定义一致。

### 4.3 六电机反馈

电机顺序固定使用 ROS 侧规范命名：

- `left_hip`
- `left_knee`
- `left_wheel`
- `right_hip`
- `right_knee`
- `right_wheel`

每个电机至少包含：

- `position`：位置观测，进入 ROS 后统一为 `rad`。
- `velocity`：速度观测，进入 ROS 后统一为 `rad/s`。
- `feedback_torque` 或 `feedback_current`：反馈力矩或电流，用于调试和安全诊断。
- `online`：电机在线状态。

若 STM32 内部使用 CAN ID、电机原始角度、编码器计数或角度制，必须在 STM32 或 bridge 映射层消解，不得泄漏到上层控制器。

当前硬件腿部角度口径：

- 仿真侧由原始关节角叠加 offset 得到 `hip_absolute`、`calf_absolute`。
- STM32 上报的髋和小腿角已经是世界坐标系 absolute 角。
- `left_hip` / `right_hip` 的 `position` 直接作为 `hip_absolute`。
- `left_knee` / `right_knee` 的 `position` 在控制语义中直接作为 `calf_absolute`。
- ROS bridge 不再对 STM32 上传的髋/小腿角叠加仿真 offset。

### 4.4 安全与诊断

状态帧必须能观察通信和执行层安全状态：

- `comm_rx_error_count`：STM32 接收命令解析错误计数。
- `comm_crc_error_count`：CRC 或校验错误计数。
- `last_command_timeout`：最近一次命令是否超时。
- `safety_state`：STM32 当前安全状态，例如 disabled、enabled、timeout、estop。
- `can_motor_online_mask`：六电机 CAN 在线位图。
- `can_error_count`：CAN 或电机反馈异常计数。

## 5. ROS 到 STM32 命令下发

命令帧由 `wheel_leg_stm32_bridge` 根据 `/joint_command` 生成。

命令帧至少包含：

- `seq`：命令帧递增序号。
- `enable`：控制使能位。
- `estop`：急停或强制失能位。
- 六电机目标力矩，语义对应 `/joint_command.efforts`。

六电机目标力矩顺序与状态上报一致：

```text
left_hip, left_knee, left_wheel, right_hip, right_knee, right_wheel
```

STM32 执行前必须处理：

- 力矩最大值限幅。
- 单周期变化率限制。
- 命令超时归零或失能。
- 急停时立即进入安全输出。
- 电机离线时禁止继续对该电机输出危险命令。

## 6. 单位、方向与映射规则

ROS 侧统一单位：

- 角度：`rad`
- 角速度：`rad/s`
- 力矩：`N*m`
- 线加速度：`m/s^2`

方向约束：

- 同一关节在仿真和实机必须保持相同正方向语义。
- 电机安装方向、零点、CAN ID 映射只能存在于 STM32 或 bridge 映射层。
- `/robot_state` 的语义必须与 `docs/protocol.md` 中的公共接口一致。
- `/joint_command.efforts` 的正方向必须与对应关节正方向一致。

当前阶段允许先以低力矩悬空测试确认方向，再决定具体映射放在 STM32 侧还是 bridge 侧；但最终不得让 `wheel_leg_control` 依赖底层电机方向细节。

## 7. 异常处理要求

### 7.1 命令超时

若 STM32 在超时时间内没有收到有效命令帧：

- 进入安全状态。
- 六电机目标输出归零或失能。
- 状态帧中置位 `last_command_timeout`。
- 保留错误计数，便于 ROS 侧记录。

### 7.2 通信错误

若收到非法帧、CRC 错误或长度错误：

- 丢弃该帧。
- 不更新有效命令。
- 增加对应错误计数。
- 保持上一安全策略，不因坏帧解除急停或恢复使能。

### 7.3 电机或 CAN 异常

若任一电机离线或 CAN 反馈异常：

- 状态帧中更新在线位图和错误计数。
- 对离线电机禁止继续输出危险命令。
- 是否整车失能由后续安全策略细化，但第一版必须可观测。

## 8. 实施清单

后续实现按以下顺序推进：

1. 定义 STM32 与 ROS 串口帧头、长度、类型、序号、payload、CRC。
2. 在 STM32 侧实现串口接收状态机，手动解包 ROS 命令帧。
3. 在 `wheel_leg_stm32_bridge` 中实现串口接收状态机，手动解包 STM32 状态帧。
4. 在 STM32 侧实现状态帧周期打包发送。
5. 在 `wheel_leg_stm32_bridge` 中实现命令帧打包发送、协议错误统计和重同步。
6. 将 STM32 状态帧映射为 `/robot_state`。
7. 将 `/joint_command` 映射为 STM32 六电机力矩命令帧。
8. 加入命令超时、安全状态、错误计数和低力矩调试参数。
9. 测试 STM32 状态上报频率，从 `100Hz`、`200Hz` 开始，记录传感器读取耗时、串口占用、ROS 解包延迟、丢包和错误计数。
10. 用悬空低力矩方式逐项验证六电机方向、单位、限幅和停机行为。

当前已先在 STM32 侧加入 `USART2` 接收解包压测入口，用于模拟 ROS 命令帧接收是否跟得上：

- 文件：`firmware/stm32/App/uart_protocol_test.cpp`
- 串口：`USART2`
- 帧格式：`0xA5 0x5A type len seq_lo seq_hi payload crc_lo crc_hi`
- CRC：`CRC16-CCITT`，初值 `0xFFFF`，覆盖 `type`、`len`、`seq` 和 `payload`
- 下行压测：STM32 中断接收并统计接收字节数、成功帧数、CRC 错误、长度错误、同步丢失、序号跳变、UART 错误、帧间隔；Keil Watch 可直接观察 `uart2_protocol_test_stats`
- 上行压测：STM32 同时以 `200Hz`（`5ms` 周期）主动回传 `type=0x81` 状态帧，payload 当前固定 `128` 字节，字段顺序如下：

```text
u32 stm_tick_ms
f32 roll
f32 pitch
f32 yaw
f32 gyro_x
f32 gyro_y
f32 gyro_z
f32 acc_x
f32 acc_y
f32 acc_z
6 * f32 joint_position
6 * f32 joint_velocity
6 * f32 joint_effort
u8  online_mask
u8  safety_state
u8  last_command_timeout
u8  reserved0
u32 comm_rx_error_count
u32 comm_crc_error_count
u32 can_error_count
```

- 编码：所有多字节字段当前都按 little-endian 打包
- 上位机模拟发送工具：`tools/uart_frame_sender.py`
- ROS 侧压测节点：`ros2_ws/src/wheel_leg_stm32_bridge/src/stm32_uart_stress_node.cpp`
- `stm32_uart_stress_node` 现已兼容旧 `48` 字节诊断状态帧和当前 `128` 字节正式状态帧，避免因版本切换误判链路失败

## 9. 验收场景

文档和后续实现按以下场景验收：

- 空帧或心跳通信稳定，可统计周期、丢包、CRC 错误和解析错误。
- 控制闭环保持 `100Hz` 时，测试 STM32 状态上报 `100Hz` 与 `200Hz` 的稳定性；若资源允许，再继续测试更高频率。
- STM32 上传 IMU 和六电机反馈，ROS 能稳定映射成 `/robot_state`。
- ROS 下发六电机小力矩，STM32 在悬空状态逐个验证方向、单位和限幅。
- 停止 ROS 命令后，STM32 在超时时间内进入安全输出。
- CAN 电机掉线、串口异常、failsafe 时，对应状态字段可观测。
- 控制器仍只依赖 `/robot_state` 和 `/joint_command`，不直接依赖 STM32 协议细节。

## 10. 当前 200Hz 状态上报瓶颈与优化方案

`2026-06-26` 的最新实测表明，STM32 侧把状态发送挂到 `Data_Task` 的 `5ms` 绝对周期后，单轮循环耗时约为 `5.58ms`。这意味着：

- `Data_Task` 自身已经超过 `5ms` 预算。
- `xTaskDelayUntil(..., 5)` 基本不会真实阻塞。
- 高优先级 `Data_Task` 会持续追赶节拍，低优先级任务更难获得 CPU。
- 当前问题已经从“调度位置不对”进一步收敛为“任务体本身太慢”。

### 10.1 当前主要耗时来源

当前确认有两块会直接挤占 `Data_Task` 周期预算：

1. 阻塞式 UART 状态帧发送

- 文件：`firmware/stm32/App/uart_protocol_test.cpp`
- 现状：状态帧发送使用 `HAL_UART_Transmit(&huart2, ...)`
- 问题：该调用是同步阻塞的，发送 `136` 字节左右状态帧时，任务会一直卡住直到发送完成或超时
- 影响：在 `921600 8N1` 下，单帧线速时间接近 `1.5ms`，这是 `5ms` 预算里最硬的一段阻塞

2. 软件 I2C 分散读取 IMU 寄存器

- 文件：`firmware/stm32/Hardware/MyI2C.c`
- 现状：`JY901S_Acc()`、`JY901S_Gyro()`、`JY901S_Angle()` 会分别多次调用 `I2C_ReadReg()`
- 问题：当前从 `0x34` 到 `0x3F` 的连续寄存器区间，被拆成 9 次独立 16 位寄存器读取
- 影响：每次 `I2C_ReadReg()` 都要走完整的 `start + address + reg + repeated start + read + stop` 流程；而软件 I2C 的 `SCL/SDA` 翻转还带 `Delay_us(1)`，累计开销明显

### 10.2 UART 发送优化方案

目标是把状态帧发送从“阻塞任务”改成“后台发送”，优先释放 `Data_Task` 的 CPU 占用。

建议方案：

1. 为 `USART2` 增加 TX DMA 通道

- 当前 `usart.c` 已初始化 `USART2` 和中断，但还没有为 `huart2` 绑定 DMA handle
- 需要补 `DMA_HandleTypeDef`
- 需要在 `HAL_UART_MspInit()` 中完成 DMA 初始化和 `__HAL_LINKDMA(&huart2, hdmatx, ...)`
- 需要补充对应 DMA IRQ

2. 将状态帧发送接口从阻塞发送改为非阻塞发送

- 首选：`HAL_UART_Transmit_DMA(&huart2, ...)`
- 过渡备选：`HAL_UART_Transmit_IT(&huart2, ...)`

3. 增加发送中的状态位，避免重入

- 增加类似 `g_tx_in_flight` 的标志
- 若上一帧尚未发送完成，本轮 `5ms` 周期直接跳过，避免多个发送重叠
- 统计跳过次数，便于后续评估链路余量

4. 将发送成功统计改到发送完成回调中

- 当前 `tx_frames`、`last_tx_seq` 等统计是在 `HAL_UART_Transmit()` 返回成功后立即更新
- 改为 DMA/IT 后，应在 `HAL_UART_TxCpltCallback()` 中确认本帧真正发完，再更新统计和序号

5. 避免发送时中断接收链路

- 当前实现为了绕过同步发送冲突，会在发送前 `HAL_UART_AbortReceive_IT()`，发送后再 `RestartReceive()`
- 如果改成 DMA/IT 发送，这种做法会让收发耦合更深，也更容易引入丢字节
- 更推荐保留 RX 中断持续工作，仅对 TX 帧缓冲做最小保护

预期收益：

- 直接去掉 `Data_Task` 里约 `1.5ms` 的同步串口阻塞
- 把状态帧发送的实际占用转为 DMA/中断后台完成
- 为 `5ms` 周期重新腾出最关键的一块预算

### 10.3 IMU 读取优化方案

目标是把当前“多次独立寄存器访问”压缩成“一次连续块读”，减少软件 I2C 事务数。

建议方案：

1. 在 `MyI2C` 层新增连续读接口

建议增加类似接口：

```c
void I2C_ReadRegs(uint8_t address, uint8_t start_reg, uint8_t *buf, uint16_t len);
```

行为要求：

- 先发送设备地址和起始寄存器地址
- 再 repeated start 切到读模式
- 连续读取 `len` 个字节
- 前 `len - 1` 个字节发送 ACK，最后 1 个字节发送 NACK
- 最后 `stop`

2. 在 `JY901S` 层新增一次性快照读取接口

建议增加类似接口：

```c
void JY901S_ReadSnapshot(...);
```

或直接一次性填充 `acc/gyro/angle` 九个量。

3. 直接读取 `0x34` 到 `0x3F`

这段地址本来就是连续区间：

- `0x34~0x36`：加速度
- `0x37~0x39`：角速度
- `0x3D~0x3F`：姿态角

当前实现虽然只实际使用其中部分寄存器，但先按整段连续读更简单稳妥。即使中间顺带读到未使用字段，也通常比多次小事务更省时。

4. 在任务里只做一次解析

- 连续读得到一段原始字节缓存
- 由 `JY901S` 层统一组合高低字节并完成比例换算
- `Data_Task` 只调用一次读取函数，不再逐项访问

预期收益：

- 明显减少 `start/stop/repeated-start` 次数
- 明显减少 `Delay_us(1)` 造成的累计开销
- 让 IMU 采样耗时从“多次小阻塞”收敛为“一次较短阻塞”

### 10.4 建议实施顺序

优先顺序建议固定为：

1. 先做 `USART2 TX DMA/IT`
- 这是当前最确定、最直接的减时项

2. 再做 `JY901S` 连续读
- 这是第二个主要耗时来源，也是让 `Data_Task` 真正回到 `5ms` 内的关键项

3. 两项完成后重新复测
- 记录 `Data_Task` 单轮耗时
- 记录 `200Hz` 状态帧是否稳定
- 记录 `tx_errors`、`crc_errors`、`sync_losses`、`rx_seq_gaps`

如果两项完成后 `Data_Task` 仍明显超过 `5ms`，再考虑把状态发送彻底挪出 `Data_Task`，单独放入独立 `State_Tx_Task`。

## 11. 树莓派 UART4 压测步骤

本阶段建议用树莓派 UART4 对接 STM32 USART2，在树莓派/ROS 环境里跑协议帧压测。目标是先确认物理串口链路、波特率和两侧手动解包稳定，再接入正式 `wheel_leg_stm32_bridge`。

### 11.1 接线

按 UART 交叉连接：

```text
Raspberry Pi UART4 TX  -> STM32 USART2 RX / PA3
Raspberry Pi UART4 RX  <- STM32 USART2 TX / PA2
Raspberry Pi GND       -- STM32 GND
```

注意：

- 必须共地。
- 两侧都应使用 `3.3V TTL` 电平。
- 不要把 TX 接 TX、RX 接 RX。
- 当前 STM32 USART2 默认 `921600 8N1`。

树莓派 UART 设备名以实际系统为准。当前工具默认会启用两个 UART overlay，并优先检测 `/dev/ttyAMA3`、`/dev/ttyAMA4`；本轮若指定 UART4，优先使用 `/dev/ttyAMA4`。

### 10.2 树莓派 UART 配置

在树莓派上执行：

```bash
cd ~/wheel_leg_ws
sudo ./tools/uart_loopback.py configure
sudo reboot
```

重启后查看 UART 状态：

```bash
cd ~/wheel_leg_ws
./tools/uart_loopback.py status
ls -l /dev/ttyAMA3 /dev/ttyAMA4
```

若 `/dev/ttyAMA4` 不存在，以 `status` 输出和 `/proc/device-tree/aliases` 为准确认 UART4 对应的 tty 设备。

### 10.3 ROS 环境下发送协议帧

加载 ROS/项目环境：

```bash
cd ~/wheel_leg_ws
source /opt/ros/jazzy/setup.bash
source ./ros2_ws/install/local_setup.bash
```

从树莓派 UART4 向 STM32 USART2 发送模拟 ROS 命令帧：

```bash
./tools/uart_frame_sender.py \
  --port /dev/ttyAMA4 \
  --baud 921600 \
  --rate-hz 200 \
  --payload-len 32 \
  --duration 60
```

如果系统中 UART4 不是 `/dev/ttyAMA4`，把 `--port` 改成实际设备。

如果希望直接在 ROS 2 图里运行压测节点，先编译：

```bash
cd ~/wheel_leg_ws/ros2_ws
colcon build --packages-select wheel_leg_stm32_bridge
source ./install/local_setup.bash
```

然后启动 ROS 侧串口压测节点：

```bash
ros2 run wheel_leg_stm32_bridge stm32_uart_stress_node \
  --ros-args \
  -p serial_device:=/dev/ttyAMA4 \
  -p baud_rate:=921600 \
  -p rate_hz:=200.0 \
  -p payload_len:=32 \
  -p report_period_sec:=1.0
```

该节点会持续发送与 STM32 当前测试入口一致的协议帧，并发布：

- `/stm32_bridge/uart_stress/status_text`
- `/stm32_bridge/uart_stress/counters`

其中 `counters` 字段顺序固定为：

```text
frames_attempted, frames_sent, bytes_sent, write_errors, partial_writes, deadline_misses, last_seq
```

ROS 侧重点关注：

- `frames_sent / frames_attempted` 是否持续接近 `1.0`
- `write_errors == 0`
- `partial_writes == 0`
- `deadline_misses` 是否持续增长

如果只看终端日志，不订阅 topic 也可以；节点每 2 秒会输出一次统计摘要。

当前 `stm32_uart_stress_node` 对 `/stm32_bridge/uart_stress/stm32_status` 的发布规则为：

- 若收到旧 `48` 字节诊断帧，字段顺序仍为：

```text
stm_tick_ms, rx_bytes, frames_ok, crc_errors, length_errors, sync_losses,
rx_seq_gaps, uart_errors, last_rx_seq, last_rx_type, last_rx_len,
min_frame_gap_ms, max_frame_gap_ms, last_rx_age_ms
```

- 若收到当前 `128` 字节正式状态帧，字段顺序为：

```text
stm_tick_ms, online_mask, safety_state, last_command_timeout,
comm_rx_error_count, comm_crc_error_count, can_error_count
```

### 10.4 STM32 侧观察项

在 Keil Watch 中观察：

```text
uart2_protocol_test_stats
```

重点看：

- `frames_ok`：成功解包帧数。
- `crc_errors`：CRC 错误计数。
- `length_errors`：长度错误计数。
- `sync_losses`：帧同步丢失计数。
- `uart_errors`：UART 硬件/HAL 错误计数。
- `last_seq`：最新帧序号。
- `min_frame_gap_ms` / `max_frame_gap_ms`：帧间隔范围。

正式测试前需要先清零统计。可以重新上电，或在调试器里调用：

```cpp
UartProtocolTest_ResetStats();
```

### 10.5 测试矩阵

先固定 `921600` 波特率，按以下顺序测试：

```bash
./tools/uart_frame_sender.py --port /dev/ttyAMA4 --baud 921600 --rate-hz 200 --payload-len 16 --duration 60
./tools/uart_frame_sender.py --port /dev/ttyAMA4 --baud 921600 --rate-hz 200 --payload-len 32 --duration 60
./tools/uart_frame_sender.py --port /dev/ttyAMA4 --baud 921600 --rate-hz 200 --payload-len 64 --duration 60
./tools/uart_frame_sender.py --port /dev/ttyAMA4 --baud 921600 --rate-hz 200 --payload-len 96 --duration 60
```

若 `200Hz` 稳定，再提高频率：

```bash
./tools/uart_frame_sender.py --port /dev/ttyAMA4 --baud 921600 --rate-hz 300 --payload-len 64 --duration 60
./tools/uart_frame_sender.py --port /dev/ttyAMA4 --baud 921600 --rate-hz 500 --payload-len 64 --duration 60
```

若 `921600` 稳定，再测试更高波特率。两侧必须同时改波特率：

```bash
./tools/uart_frame_sender.py --port /dev/ttyAMA4 --baud 1000000 --rate-hz 200 --payload-len 64 --duration 60
./tools/uart_frame_sender.py --port /dev/ttyAMA4 --baud 2000000 --rate-hz 200 --payload-len 64 --duration 60
```

### 10.6 判定标准

每轮测试结束后，记录发送端输出和 STM32 侧统计。

通过标准：

- `frames_ok` 接近发送端 `sent`。
- `crc_errors == 0`。
- `length_errors == 0`。
- `uart_errors == 0`。
- `last_seq` 持续递增，没有明显跳变。
- `max_frame_gap_ms` 没有异常大尖峰。

说明：

- 如果测试前用串口调试助手发过普通文本，`sync_losses` 可能已经增加；这不代表协议帧丢包。正式压测前先清零统计。
- 当前 STM32 接收实现是单字节中断接收，用于先验证链路和最坏情况下的解包开销。若高频或大 payload 下 `uart_errors` 增加，下一步改为 DMA 环形缓冲，但仍然保持手动解包。
- ROS 侧若在 `921600` 下已经出现 `write_errors`、`partial_writes` 或明显的 `deadline_misses`，先优先排查 UART4 设备名、串口权限、overlay 配置和串口占用情况。

## 11. 与现有文档关系

- `docs/protocol.md` 继续固定仿真和实机共用的 Topic、命名、单位和方向边界。
- `docs/stm32_hardware_integration.md` 继续作为硬件接入与实机闭环总任务。
- 本文档专门记录 STM32 与 ROS 第一版通信内容、字段和验收任务。

## 12. 实测记录

### 2026-06-25 UART4 <-> USART2

- 实测端口：树莓派 `/dev/ttyAMA4` 对接 STM32 `USART2`
- 实测波特率：`921600 8N1`
- 旧版 `stm32_uart_stress_node` 按 `48` 字节状态帧解包时表现为 `rx_ok=0`、`rx_sync` 持续增长，但原始串口抓包已能看到合法帧头 `a5 5a 81 80`，说明当时不是物理链路中断，而是 ROS 侧仍按旧状态帧格式解析
- 正式 `wheel_leg_stm32_bridge_node` 现场验证通过：`/stm32_bridge/status_text` 为 `state=ok state_stale=false`，`/stm32_bridge/counters` 观测到 `rx_frames_ok=849` 且 `rx_crc_errors=0`、`rx_length_errors=0`、`rx_sync_losses=0`
- 继续运行后，`/stm32_bridge/counters` 观测到 `rx_frames_ok=3101`，说明 STM32 到 ROS 上行通信稳定
- ROS 侧向 `/joint_command` 发布全零六关节力矩命令后，bridge 侧 `tx_frames_sent` 从 `0` 增加到 `4`，说明 ROS 到 STM32 下行写串口正常
- 当未持续发送命令时，状态中的 `safety=timeout` 为 STM32 `100ms` 命令超时保护的预期行为，不作为链路故障判据
- 本次结论：`wheel_leg_stm32_bridge_node` 已可与当前 STM32 固件正常通信；`stm32_uart_stress_node` 需要与 `128` 字节状态帧保持兼容，避免误报

### 12.1 2026-06-25 UART4 <-> USART2 首轮联调

测试环境：

- Raspberry Pi 串口设备：`/dev/ttyAMA4`
- STM32 串口：`USART2`
- 参数：`921600 8N1`
- ROS 侧压测节点：`stm32_uart_stress_node`
- 下行发送参数：`200Hz`、`payload_len=32`
- STM32 上行状态帧：`type=0x81`、`200Hz`、`payload_len=48`

第一次测试现象：

- 当时 Raspberry Pi 与 STM32 未共地。
- ROS 侧下行发送统计正常，`write_errors=0`、`partial_writes=0`。
- 但 ROS 侧无法按 `0xA5 0x5A` 帧格式解出任何合法 `type=0x81` 状态帧。
- `/dev/ttyAMA4` 上能读到原始字节流，但内容表现为噪声，说明物理链路参考地缺失会直接导致协议解包失败。

修正后结果：

- 补上 `Raspberry Pi GND -- STM32 GND` 共地后，链路恢复正常。
- ROS 侧可以稳定解出 STM32 回传的合法 `type=0x81` 状态帧。
- 这次联调确认了“必须共地”不仅是接线规范，也是本链路是否能建立协议通信的前置条件。

### 12.2 2026-06-25 5 秒复测结果

复测参数保持不变：`/dev/ttyAMA4`、`921600 8N1`、ROS 下行 `200Hz`、`payload_len=32`。

ROS 侧发送统计：

- `attempted=801`
- `sent=801`
- `write_errors=0`
- `partial_writes=0`
- `deadline_misses=0`

ROS 侧接收 STM32 状态帧统计：

- `valid_type81=1002`
- `crc_err=0`

从 STM32 `type=0x81` 状态帧解出的 5 秒窗口增量：

- `delta_stm_tick_ms = 5005`
- `delta_seq = 1001`
- `delta_frames_ok = 880`
- `delta_rx_bytes = 35200`
- `delta_crc_errors = 0`
- `delta_length_errors = 0`
- `delta_sync_losses = 0`
- `delta_rx_seq_gaps = 1`
- `delta_uart_errors = 0`

STM32 侧 `USART1` 调试打印观察：

- 早期一次误判记录中，STM32 侧表现为 `tx` 持续增长，但 `rx_ok`、`last_rx` 长时间不变；后续确认当时 ROS 侧压测节点未启动，因此只能证明 STM32 上行发送正常，不能据此判断链路整体异常。
- 在 ROS 压测节点正确启动后的稳定窗口内，STM32 侧打印可见 `rx_ok` 与 `tx` 同步持续增长，`last_rx`、`last_tx` 也连续前进，说明双向链路都在工作。
- 现场串口打印样例如下：

```text
uart2 rx_ok=4397 rx_crc=94 rx_gap=47 tx=4600 tx_err=0 last_rx=5991 last_tx=4599
uart2 rx_ok=4597 rx_crc=94 rx_gap=47 tx=4800 tx_err=0 last_rx=6191 last_tx=4799
uart2 rx_ok=4797 rx_crc=94 rx_gap=47 tx=5000 tx_err=0 last_rx=6391 last_tx=4999
uart2 rx_ok=4997 rx_crc=94 rx_gap=47 tx=5200 tx_err=0 last_rx=6591 last_tx=5199
uart2 rx_ok=5197 rx_crc=94 rx_gap=47 tx=5400 tx_err=0 last_rx=6791 last_tx=5399
uart2 rx_ok=5397 rx_crc=94 rx_gap=47 tx=5600 tx_err=0 last_rx=6991 last_tx=5599
uart2 rx_ok=5597 rx_crc=94 rx_gap=47 tx=5800 tx_err=0 last_rx=7191 last_tx=5799
uart2 rx_ok=5797 rx_crc=94 rx_gap=47 tx=6000 tx_err=0 last_rx=7391 last_tx=5999
uart2 rx_ok=5997 rx_crc=94 rx_gap=47 tx=6200 tx_err=0 last_rx=7591 last_tx=6199
uart2 rx_ok=6197 rx_crc=94 rx_gap=47 tx=6400 tx_err=0 last_rx=7791 last_tx=6399
uart2 rx_ok=6345 rx_crc=117 rx_gap=59 tx=6600 tx_err=0 last_rx=7988 last_tx=6599
```

由 STM32 侧打印可以直接得到：

- `tx_err=0`，说明 STM32 `USART2` 上行状态帧发送没有出现 HAL 发送失败。
- `rx_ok` 持续增长，说明 ROS 下行压测帧已被 STM32 持续成功解包。
- `last_rx` 与 `last_tx` 基本按固定步长推进，说明两侧周期配置和序号推进逻辑一致。
- `rx_crc`、`rx_gap` 虽然在稳定窗口内仍有小幅增长，但相对累计成功帧占比很低；当前状态可以认为“链路已打通，可进入后续 ROS 映射和长时间稳定性观察阶段”。

当前结论：

- UART4 到 STM32 USART2 的双向协议通信已打通。
- STM32 到 ROS 的 `type=0x81` 上行状态帧在本轮 5 秒复测中稳定。
- ROS 到 STM32 的命令帧发送链路正常，STM32 已持续成功解包下行命令帧。
- 本轮窗口内 `CRC`、长度、同步和 `UART` 错误新增均为 `0`，链路质量明显优于未共地时的失败状态。
- `delta_rx_seq_gaps = 1` 说明仍存在轻微偶发序号跳变，后续可在更长时间窗口继续观察，但当前已经满足“首轮链路打通”目标。

### 12.3 2026-06-25 正式通信节点 V1 代码落地

本轮已按“正式通信节点 V1”计划完成第一版代码接线，但当前结论仍属于“代码已落地，待板级联调验证”，不是最终硬件验收结论。

本轮已完成的代码改动：

- `wheel_leg_stm32_bridge` 已从占位节点切换为正式串口 bridge。
- ROS 侧 bridge 已实现 `0xA5 0x5A` 帧头、`type/len/seq/payload/crc16-ccitt` 解包与命令打包。
- ROS 侧 bridge 已发布：
  - `/robot_state`
  - `/imu`
  - `/joint_states`
- ROS 侧 bridge 已订阅：
  - `/joint_command`
  - `/rc/status`
- `wheel_leg_msgs/msg/RcStatus.msg` 已新增 `estop_active` 字段。
- `wheel_leg_rc` 已将急停默认通道固定为 `channel 7`，并按“低值端触发急停”输出 `estop_active=true`。
- bridge 已把 `RC ch7` 急停并入下行命令帧门控：
  - `estop_active=true` 时强制下发 `estop=1`
  - 同时强制 `enable=0`
  - 六路力矩清零
- `hw.launch.py` 已增加正式 bridge 的串口和发布参数透传。
- `rc.launch.py` 已增加 `estop_channel` 与 `estop_active_below` launch 参数，默认保持 `7 / true`。

STM32 侧本轮已完成的代码改动：

- `uart_protocol_test.cpp` 已从纯压测 payload 升级为正式协议对端。
- STM32 侧已实现下行命令帧解析：
  - `enable`
  - `estop`
  - 六路 `float32` 力矩命令
- STM32 侧已实现基础执行层保护：
  - 命令超时失能
  - 急停失能
  - 六路力矩限幅
  - 单周期斜率限制
- STM32 侧已改为周期回传真实状态帧：
  - `stm_tick_ms`
  - IMU 角度/角速度/加速度
  - 六电机位置/速度/反馈力矩
  - `online_mask`
  - `safety_state`
  - `last_command_timeout`
  - 通信与 CAN 诊断计数
- `Car.cpp` 已改为从通信模块读取六路执行力矩，而不是继续使用单一测试 `target`。

本轮已完成的软件验证：

- ROS 侧已在本机完成以下包编译通过：
  - `wheel_leg_msgs`
  - `wheel_leg_bridge`
  - `wheel_leg_rc`
  - `wheel_leg_stm32_bridge`
  - `wheel_leg_control`
  - `wheel_leg_bringup`
- `RcStatus` 新接口已可正确导出并被 ROS 侧包依赖。

本轮尚未完成的验证：

- 尚未在当前环境完成 STM32 工程编译验证。
- 尚未完成正式 `type=0x81` 新 payload 与 ROS bridge 的上板联调。
- 尚未完成 `RC ch7 -> bridge -> command estop -> STM32 safety_state` 的整链硬件验证。
- 尚未完成六电机方向、单位、限幅和斜率限制的悬空验证。
- 尚未完成 `/robot_state` 新来源下的 200Hz 实机闭环联调。

因此当前阶段状态应理解为：

- 压测链路：`[v] 已打通`
- 正式 V1 代码：`[x] 已实现`
- 正式 V1 硬件闭环：`[~] 待联调验证`

### 12.4 2026-06-25 正式状态帧发送失败问题定位

本节记录 `2026-06-25` 针对正式 `type=0x81` 状态帧发送异常的定位过程、结论以及临时绕过方案。

现象一：ROS 侧 `/stm32_bridge/counters` 表现异常

- 计数样例：`[0, 14576, 0, 1092082, 0, 0, 0]`
- 对应含义：
  - `rx_frames_ok = 0`
  - `rx_crc_errors` 持续增长
  - `rx_length_errors = 0`
  - `rx_sync_losses` 很大
  - `tx_frames_sent = 0`
- 这说明 ROS 侧没有成功解出任何一帧合法状态帧，但当时还不能仅凭这一点判断根因在 ROS 解包侧。

现象二：树莓派直接抓取 `/dev/ttyAMA4` 原始上行字节

- 在停掉 `hw.launch.py` 后，直接读取 `/dev/ttyAMA4` 的 256 字节原始流。
- 字节流中频繁出现 `a5 5a 81 80`，表面上看像是正式 `type=0x81` 状态帧。
- 但按当前源码约定的 `payload_len=128`、`CRC(type,len,seq,payload)` 去校验时，原始流无法通过 CRC。
- 同时，连续帧头实际出现的间距约为 `75` 到 `77` 字节，而不是新协议应有的完整帧长度。
- 因此，ROS 侧看到的是“看起来像新帧头”的字节流，但内容与当前正式协议定义并不一致。

现象三：STM32 调试打印直接显示 `USART2` 上行发送失败

调试打印样例：

```text
uart2 rx_ok=0 rx_crc=0 rx_gap=0 tx=0 tx_err=595 last_rx=0 last_tx=0
uart2 rx_ok=0 rx_crc=0 rx_gap=0 tx=0 tx_err=694 last_rx=0 last_tx=0
uart2 rx_ok=0 rx_crc=0 rx_gap=0 tx=0 tx_err=793 last_rx=0 last_tx=0
uart2 rx_ok=0 rx_crc=0 rx_gap=0 tx=0 tx_err=892 last_rx=0 last_tx=0
uart2 rx_ok=0 rx_crc=0 rx_gap=0 tx=0 tx_err=991 last_rx=0 last_tx=0
uart2 rx_ok=0 rx_crc=0 rx_gap=0 tx=0 tx_err=1090 last_rx=0 last_tx=0
uart2 rx_ok=0 rx_crc=0 rx_gap=0 tx=0 tx_err=1189 last_rx=0 last_tx=0
uart2 rx_ok=0 rx_crc=0 rx_gap=0 tx=0 tx_err=1288 last_rx=0 last_tx=0
uart2 rx_ok=0 rx_crc=0 rx_gap=0 tx=0 tx_err=1387 last_rx=0 last_tx=0
```

这组打印可以直接说明：

- `tx=0`：STM32 `USART2` 正式状态帧一帧都没有成功发出。
- `tx_err` 持续增长：发送阶段持续失败，失败点发生在 ROS 侧解包之前。
- `rx_ok=0`、`last_rx=0`：本轮同时也没有收到 ROS 下行的合法命令帧。

本轮结论：

- 这一次问题的根因不是 ROS 侧解包逻辑。
- 根因已经前移到 STM32 侧更前面的发送链路：`USART2` 正式状态帧发送本身持续失败。
- ROS 侧观察到的 CRC 错误和同步丢失，更应视为下游症状，而不是主因。

进一步诊断：

- 在 STM32 侧为 `HAL_UART_Transmit(&huart2, ...)` 增加 `HAL_StatusTypeDef`、`HAL_UART_GetError()`、`huart2.gState`、`huart2.RxState` 诊断打印后，失败样例表现为：

```text
uart2 rx_ok=0 rx_crc=0 rx_gap=0 tx=0 tx_err=2377 busy=0 to=2377 herr=0 tx_st=3 tx_ec=0 g=32 rxs=34 last_rx=0 last_tx=0
uart2 rx_ok=0 rx_crc=0 rx_gap=0 tx=0 tx_err=2476 busy=0 to=2476 herr=0 tx_st=3 tx_ec=0 g=32 rxs=34 last_rx=0 last_tx=0
uart2 rx_ok=0 rx_crc=0 rx_gap=0 tx=0 tx_err=2575 busy=0 to=2575 herr=0 tx_st=3 tx_ec=0 g=32 rxs=34 last_rx=0 last_tx=0
```

- 这说明失败类型不是 `HAL_BUSY` 或 `HAL_ERROR`，而是稳定的 `HAL_TIMEOUT`。
- `tx_ec=0` 说明当时没有新增 UART 硬件错误码。
- `g=32` 对应 `HAL_UART_STATE_READY`，`rxs=34` 对应 `HAL_UART_STATE_BUSY_RX`，也就是 `USART2` 正长期挂着 `HAL_UART_Receive_IT(..., 1)` 的接收状态。
- 该组合说明问题已进一步收敛到：同一个 `huart2` 上，持续 `Receive_IT` 与当前阻塞式 `HAL_UART_Transmit` 的组合会使发送侧在等待标志位时超时。

临时绕过修改：

- 在 `firmware/stm32/App/uart_protocol_test.cpp` 的 `TrySendStatusFrame()` 中，若发现 `huart2.RxState == HAL_UART_STATE_BUSY_RX`，先执行 `HAL_UART_AbortReceive_IT(&huart2)`。
- 状态帧发送完成后，再调用 `RestartReceive()` 恢复单字节中断接收。
- 同时把发送超时从 `5ms` 放宽到 `20ms`，并打印 `USART2->ISR`、`CR1`、`CR3` 快照。

应用绕过后的调试打印样例：

```text
uart2 rx_ok=0 rx_crc=0 rx_gap=0 tx=1519 tx_err=0 busy=0 to=0 herr=0 abort_rx=1519 tx_st=0 tx_ec=0 g=32 rxs=34 isr=006000d0 cr1=0000000d cr3=00000000 last_rx=0 last_tx=1518
uart2 rx_ok=0 rx_crc=0 rx_gap=0 tx=1585 tx_err=0 busy=0 to=0 herr=0 abort_rx=1585 tx_st=0 tx_ec=0 g=32 rxs=34 isr=006000d0 cr1=0000000d cr3=00000000 last_rx=0 last_tx=1584
uart2 rx_ok=0 rx_crc=0 rx_gap=0 tx=1651 tx_err=0 busy=0 to=0 herr=0 abort_rx=1651 tx_st=0 tx_ec=0 g=32 rxs=34 isr=006000d0 cr1=0000000d cr3=00000000 last_rx=0 last_tx=1650
uart2 rx_ok=0 rx_crc=0 rx_gap=0 tx=1717 tx_err=0 busy=0 to=0 herr=0 abort_rx=1717 tx_st=0 tx_ec=0 g=32 rxs=34 isr=006000d0 cr1=0000000d cr3=00000000 last_rx=0 last_tx=1716
```

绕过后的结论：

- `tx_err=0` 且 `tx` 持续增长，说明 STM32 `USART2` 正式状态帧上行发送已恢复正常。
- `abort_rx` 与 `tx` 基本同步增长，进一步支持“持续 `Receive_IT` 与阻塞式 `Transmit` 冲突”这一根因判断。
- 该修改证明本轮主要问题不在 CRC 算法、协议打包内容或物理 TX 线本身，而在 STM32 侧同一 UART 的收发方式组合。
- 当前日志仍保持 `rx_ok=0`、`last_rx=0`，说明剩余问题已转移到下行命令未进入 STM32，不能再把当前链路问题归因到上行发送。

当前记录状态：

- 已完成正式状态帧发送失败的根因缩小与临时绕过验证。
- 当前 `USART2` 上行状态发送恢复正常。
- 当前仍待继续排查 ROS/树莓派到 STM32 的下行命令接收链路。
- 当前“发送前 abort 接收、发送后重启接收”方案只作为联调阶段临时绕过，不建议直接作为最终正式实现。

### 10.5 `2026-06-26` 当晚继续跟进后的最终根因与修复

在继续把阻塞发送改为 `HAL_UART_Transmit_DMA(&huart2, ...)` 后，现场日志一度表现为：

```text
uart2 rx_ok=0 rx_crc=0 rx_gap=0 tx=0 tx_err=0 ... g=33 rxs=34 ... cr3=00000081 ... skip=1999
```

后续又补充了 DMA/DMAMUX 诊断字段，典型样例如下：

```text
uart2 rx_ok=0 rx_crc=0 rx_gap=0 tx=0 tx_err=0 ... g=33 rxs=34 ... cr3=00000081 ...
dma_st=2 ndtr=0 dcr=00000000 dfcr=00000000 lisr=00000000 hisr=00000000 mux=0000002c hdmatx=24006930 parent=24006808 skip=2199
```

这组数据说明：

- `g=33` 对应 `HAL_UART_STATE_BUSY_TX`，`rxs=34` 对应 `HAL_UART_STATE_BUSY_RX`。
- `skip` 持续增长，说明第一帧 DMA 发送请求发起后，`g_tx_in_flight` 长期没有被发送完成回调清零。
- 但 `ndtr=0`、`dcr=0`、`lisr=0`、`hisr=0` 又表明 DMA stream 自身并没有真正进入工作状态。
- `hdmatx` 和 `parent` 都非零，说明 `__HAL_LINKDMA()` 已经生效，不是 UART handle 没绑 DMA。

最终根因不是协议内容，也不是 `HAL_UART_Transmit_DMA()` 本身，而是 **实际参与构建的工程入口已经从 CubeMX 默认的 `main.c` 切到了自定义 `main.cpp`，但 `main.cpp` 没有同步调用 `MX_DMA_Init()`；同时 Keil 工程文件里也没有把 `dma.c` 编进目标**。

核对结果如下：

- Keil 工程实际入口文件：`firmware/stm32/Core/Src/main.cpp`
- `main.cpp` 原始版本初始化了 `GPIO/FDCAN/USART/TIM`，但没有调用 `MX_DMA_Init()`
- `firmware/stm32/MDK-ARM/wheel_leg_robort.uvprojx` 初始状态也未收录 `../Core/Src/dma.c`

最终修复内容：

1. 在 `firmware/stm32/Core/Src/main.cpp` 中补 `#include "dma.h"`。
2. 在外设初始化序列中补 `MX_DMA_Init();`，再初始化 `USART2`。
3. 在 `firmware/stm32/MDK-ARM/wheel_leg_robort.uvprojx` / `.uvoptx` 中把 `../Core/Src/dma.c` 正式加入工程。
4. 保留 `USART2_IRQHandler() -> HAL_UART_IRQHandler(&huart2)`，保证 DMA 发送完成后的 UART `TC` 收尾中断能进入 HAL。
5. 当前 HAL 版本里没有 `__HAL_RCC_DMAMUX1_CLK_ENABLE()` 宏，因此不要额外保留这行；本版本按 `MX_DMA_Init()` 中现有 `__HAL_RCC_DMA1_CLK_ENABLE()` 工作即可。

应用最终修复后的上行日志样例：

```text
uart2 rx_ok=0 rx_crc=0 rx_gap=0 tx=1799 tx_err=0 busy=0 to=0 herr=0 abort_rx=0 tx_st=0 tx_ec=0 g=33 rxs=34 isr=00600010 cr1=0000002d cr3=00000081 last_rx=0 last_tx=1798 dma_st=2 ndtr=130 dcr=0010045f dfcr=00000000 lisr=00000000 hisr=00000000 mux=0000002c hdmatx=24006930 parent=24006808 skip=0
uart2 rx_ok=0 rx_crc=0 rx_gap=0 tx=1999 tx_err=0 busy=0 to=0 herr=0 abort_rx=0 tx_st=0 tx_ec=0 g=33 rxs=34 isr=00600010 cr1=0000002d cr3=00000081 last_rx=0 last_tx=1998 dma_st=2 ndtr=129 dcr=0010045f dfcr=00000000 lisr=00000000 hisr=00000000 mux=0000002c hdmatx=24006930 parent=24006808 skip=0
```

最终结论：

- `tx` 与 `last_tx` 每秒增加约 `200`，说明 STM32 `USART2` 上行正式状态帧已经稳定跑到 `200Hz`。
- `tx_err=0`，说明 DMA 发送链路已恢复正常。
- `skip=0`，说明当前 `5ms` 周期下没有因为上一帧未发完而跳过周期。
- 日志中偶尔看到 `g=33`、`cr3=0x81`、`ndtr` 非零，属于采样瞬间落在 DMA 正在发送本帧的中间态，不再表示卡死。
- 在 ROS 侧未开启时，`rx_ok=0`、`last_rx=0` 是预期现象，不能再据此判断上行失败。

当前建议状态更新为：

- STM32 单边上行 `200Hz` 已验证通过。
- 前述“发送前 abort 接收、发送后重启接收”的联调绕过方案可以保留在文档中作为阶段性排查记录，但不再作为当前主线方案。
- 下一步应切回 ROS 侧联调，继续验证 `wheel_leg_stm32_bridge` 在 `200Hz` 上行下的接收稳定性、CRC/长度错误计数，以及 `/joint_command` 下行接收情况。

### 10.6 本阶段收口

截至 `2026-06-26`，本文档中“STM32 上行状态帧提频到 `200Hz`”这一部分可以正式收口，结论如下：

- `USART2` 状态帧上行已经稳定达到 `200Hz`
- 当前实现采用 `HAL_UART_Transmit_DMA(&huart2, ...)`
- `Data_Task` 内 IMU 读取已改为单次快照读取，不再保留 9 次分散寄存器访问
- 当前 `5ms` 周期下 `skip=0`，说明没有因为上一帧未发送完成而丢周期
- 当前阶段已不再需要依赖“发送前 abort RX、发送后重启 RX”的临时绕过方案

因此，`200Hz` 这一部分的后续工作不再是继续追查 STM32 单边上行发送本身，而是转入：

- ROS 侧 `wheel_leg_stm32_bridge` 接收稳定性验证
- ROS 下行 `/joint_command -> STM32` 接收链路验证
- 在 `200Hz` 上行、`200Hz` 控制闭环条件下的整链联调

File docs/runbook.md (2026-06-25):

# 运行归档

## 工作区约定

- `ros2_ws/` 是正式 ROS2 工作区。
- `ros2_ws/build`、`ros2_ws/install`、`ros2_ws/log` 只服务 ROS2 构建，因此固定收口在 `ros2_ws/` 下。
- 仓库根目录同时包含 `firmware/`、`sim/`、`scripts/`、`docs/`，不再把根目录直接当成 ROS2 workspace。

这样做的目的：

- ROS2 构建产物和固件、仿真资源、文档分离。
- 不同设备同步同一仓库时，构建边界更清楚。
- `scripts/*.sh` 可以稳定地只针对 `ros2_ws/` 工作，而不污染仓库根目录。

## 目录职责

- `ros2_ws/`: ROS2 包、`colcon` 构建产物
- `firmware/`: STM32 固件
- `sim/mujoco/runtime/`: MuJoCo runtime 源码
- `sim/mujoco/scenes/scence.xml`: MuJoCo 场景入口
- `scripts/`: 统一构建和启动脚本

## 构建

在仓库根目录执行：

```bash
cd ~/wheel_leg_ws
```

核心控制链：

```bash
./scripts/build.sh core
```

主机构建仿真链：

```bash
./scripts/build.sh sim
```

树莓派构建遥控/硬件链：

```bash
./scripts/build.sh pi
```

全部正式包：

```bash
./scripts/build.sh all
```

清理 ROS2 构建产物：

```bash
./scripts/build.sh clean
```

## 启动分工

### 主机

仿真 + controller：

```bash
./scripts/run_host.sh sim
```

只跑 MuJoCo 仿真，不让 ROS controller 接管：

```bash
./scripts/run_host.sh sim_only
```

只跑 controller：

```bash
./scripts/run_host.sh control_only
```

### 树莓派

只跑遥控：

```bash
./scripts/run_pi.sh rc
```

硬件主链：

```bash
./scripts/run_pi.sh hw
```

只跑硬件控制主链，不起 STM32 bridge：

```bash
./scripts/run_pi.sh hw_core
```

UART4 到 STM32 USART1 通信压测：

```bash
sudo ./tools/uart_loopback.py configure
sudo reboot
```

重启后：

```bash
./tools/uart_loopback.py status
source /opt/ros/jazzy/setup.bash
source ./ros2_ws/install/local_setup.bash
./tools/uart_frame_sender.py --port /dev/ttyAMA4 --baud 921600 --rate-hz 200 --payload-len 32 --duration 60
```

详细判据见 `docs/stm32_ros_comm_task.md`。

## 手动方式

手动加载环境：

```bash
cd ~/wheel_leg_ws
source /opt/ros/jazzy/setup.bash
source ./ros2_ws/install/local_setup.bash
```

手动跑 MuJoCo 二进制：

```bash
./ros2_ws/build/wheel_leg_simulate_ros2/wheel_leg_simulate ./sim/mujoco/scenes/scence.xml
```

## 兼容入口

当前仍保留兼容脚本：

```bash
./scripts/run.sh sim
./scripts/run.sh sim_only
./scripts/run.sh hw
./scripts/run.sh rc
./scripts/run.sh control_only
```

但后续建议优先使用：

- `scripts/run_host.sh`
- `scripts/run_pi.sh`

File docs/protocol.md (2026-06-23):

# 轮腿机器人统一接口与通信边界文档

## 1. 文档目标

本文档固定仿真与实机共用的上层接口语义，为后续 STM32 通信实现和 `ros2_control` 收口提供一致约束。

本轮不定义最终 STM32 二进制帧格式的每一个字节，但先固定上层接口和下层对接原则。

## 2. 上层公共 Topic

当前阶段公共 Topic 保持不变：

- `/robot_state`
- `/joint_command`
- `/joint_states`
- `/imu`
- `/cmd_vel`
- `/control_mode`

约束：

- 仿真和实机不得为同一语义发明两套 Topic 名称。
- 上层控制器只依赖这些公共接口，不直接感知底层是 MuJoCo 还是 STM32。

## 3. 状态接口语义

### 3.1 `/robot_state`

职责：

- 作为控制器主输入。
- 聚合控制所需的机体、腿部、轮部和模式相关状态。

来源：

- 仿真模式由 `wheel_leg_sim` 生成。
- 实机模式由 `wheel_leg_stm32_bridge` 生成。

### 3.2 `/joint_states`

职责：

- 对外提供标准关节位置、速度观测。
- 服务调试、可视化和通用 ROS 工具。

### 3.3 `/imu`

职责：

- 提供机体姿态、角速度和线加速度。

当前约束：

- `frame_id` 继续使用 `base_link`
- 四元数按 ROS 标准顺序发布

## 4. 命令接口语义

### 4.1 `/joint_command`

职责：

- 作为当前阶段控制器到执行层的统一命令接口。

消息约束：

- 使用 `wheel_leg_msgs/msg/JointCommand`
- `joint_names` 使用 ROS 侧规范命名
- `efforts` 当前语义为力矩命令

### 4.2 `/cmd_vel`

职责：

- 作为统一速度控制输入。
- 可以来自遥控器、调试脚本或后续规划器。

### 4.3 `/control_mode`

职责：

- 控制站立、失能、速度控制等模式切换。

## 5. 命名约束

ROS 侧关节规范名保持为：

- `left_hip`
- `left_knee`
- `left_wheel`
- `right_hip`
- `right_knee`
- `right_wheel`

约束：

- 该命名用于 `/joint_states.name` 和 `/joint_command.joint_names`
- MuJoCo XML 命名和 STM32 内部电机编号都通过映射层转换
- 上层控制代码不直接依赖仿真或固件内部命名

## 6. 单位与方向约束

本轮先固定原则，具体数值映射在 STM32 接入时细化：

- 位置使用弧度或米，禁止混用角度制进入控制主链
- 速度使用 `rad/s`、`m/s`
- 力矩使用 `Nm`
- IMU 角速度使用 `rad/s`
- 线加速度使用 `m/s^2`

方向约束：

- 同一关节在仿真和实机必须保持相同正方向语义
- 若 STM32 底层电机安装方向相反，应在 bridge 或 firmware 侧消解，不泄漏到上层控制器

## 7. STM32 通信分层原则

Raspberry Pi 与 STM32 的长期关系固定为：

```text
wheel_leg_controller
  ↓
/joint_command
  ↓
wheel_leg_stm32_bridge
  ↓
serial / can protocol
  ↓
STM32 firmware
```

分层约束：

- `wheel_leg_control` 不解析 STM32 二进制协议
- `wheel_leg_stm32_bridge` 负责协议编解码
- `firmware/stm32` 负责执行层实时细节

## 8. 与 `ros2_control` 的衔接

本轮不直接改成 `ros2_control`，但本文档中的命名和接口语义将作为后续 `SystemInterface` 的输入条件。

后续若接入 `ros2_control`：

- `wheel_leg_hw` 负责统一 hardware 语义
- MuJoCo 和 STM32 都实现同一套 joint/state/command 约定
- 控制器层不再区分仿真和实机 backend

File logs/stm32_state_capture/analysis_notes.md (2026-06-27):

# STM32 State Capture Analysis Notes

## 2026-06-27 Static Test Round 1

### Scope

- Data files:
  - [joints_static.summary.txt](/home/tan/wheel%20_leg_ws/logs/stm32_state_capture/joints_static.summary.txt)
  - [leg_static.summary.txt](/home/tan/wheel%20_leg_ws/logs/stm32_state_capture/leg_static.summary.txt)
  - [imu_static.summary.txt](/home/tan/wheel%20_leg_ws/logs/stm32_state_capture/imu_static.summary.txt)
- Sampling rate was stable at about `200 Hz`.
- UART / ROS capture chain looked healthy for this round:
  - `frames_ok` matched sample count
  - `crc_errors = 0`
  - `length_errors = 0`
  - `sync_losses = 0`

### User Context

- IMU angular velocity is intentionally filtered inside the sensor and includes a deadband.
- Therefore, `gyro_x / gyro_y / gyro_z == 0` while static is expected for this project.
- IMU filtering conclusions should not be based on this static-zero gyro behavior alone.

### Static Noise Observations

- Joint position noise is small and usable:
  - hip and knee position variation is present but very small
  - static spread is on the order of about `1e-4 ~ 4e-4 rad`
- Joint velocity noise is visible and larger than position noise:
  - left/right hip velocity std is about `0.0067 ~ 0.0073 rad/s`
  - left/right knee velocity std is about `0.010 ~ 0.013 rad/s`
  - knee velocity is noisier than hip velocity
- Leg geometry states are already very clean:
  - `phi_std ~= 0.002 deg`
  - `length_std ~= 0.005 ~ 0.006 mm`
- Differentiated leg quantities are noisier, which is expected:
  - `length_rate_raw_std ~= 1.1 ~ 1.35 mm/s`
  - LPF replay reduces `length_rate` noise substantially

### Current Conclusions

- `joint_pos`: no extra low-pass needed for now
- `joint_vel`: likely needs low-pass, especially knee velocity
- `phi`: no extra low-pass needed for now
- `length`: no extra low-pass needed for now
- `phi_rate`: light filtering is reasonable
- `length_rate`: filtering is recommended

### Recommended First-Pass Filter Targets

- `hip_vel`: start around `20 Hz`
- `knee_vel`: start around `15 Hz`
- `phi_rate`: start around `20 Hz`
- `length_rate`: start around `10 Hz`
- `joint_pos`: start with no filter
- `phi`: start with no filter
- `length`: start with no filter

### Notes For Next Test

- Next priority is dynamic data, not another static-only decision.
- Recommended sequence:
  1. joint dynamic
  2. leg dynamic
  3. IMU dynamic
- For dynamic tests, begin with small and slow motions first so that noise and delay can be separated.

## 2026-06-27 Dynamic Test Round 1

### Scope

- Data files:
  - [joints_dynamic.summary.txt](/home/tan/wheel%20_leg_ws/logs/stm32_state_capture/joints_dynamic.summary.txt)
  - [leg_dynamic.summary.txt](/home/tan/wheel%20_leg_ws/logs/stm32_state_capture/leg_dynamic.summary.txt)
- IMU conclusions were intentionally skipped for this round.
- Capture quality remained healthy:
  - sample rate stayed near `200 Hz`
  - `crc_errors = 0`
  - `length_errors = 0`
  - `sync_losses = 0`

### Dynamic Observations

- Joint motion is large enough now to separate real motion from static noise.
- Joint velocity carries real motion content and should not be filtered too heavily.
- Knee velocity is still the noisiest joint-velocity channel, but dynamic content is now much larger than the static noise floor.
- Leg geometry channels are smooth enough:
  - `phi` and `length` track motion cleanly
  - no sign that their base signals need heavy low-pass filtering
- Rate-like leg channels still show visible amplification of noise:
  - `phi_rate_raw` contains useful motion but should only get light filtering
  - `length_rate_raw` is clearly noisier and benefits from filtering

### Practical Conclusions

- `joint_pos`:
  - keep unfiltered
- `joint_vel`:
  - filter lightly only
  - avoid strong low-pass or the motion response will become sluggish
- `phi`:
  - keep unfiltered
- `length`:
  - keep unfiltered
- `phi_rate`:
  - light low-pass is appropriate
- `length_rate`:
  - low-pass is recommended

### Updated Filter Starting Points

- `hip_vel`: `20 ~ 25 Hz`
- `knee_vel`: `15 ~ 20 Hz`
- `wheel_vel`: wait for a wheel-focused dynamic test before finalizing
- `phi_rate`: `15 ~ 20 Hz`
- `length_rate`: `8 ~ 12 Hz`
- `joint_pos`: no filter
- `phi`: no filter
- `length`: no filter

### What This Round Changed

- Static data suggested where noise exists.
- Dynamic data confirmed that:
  - `joint_vel` should be filtered only lightly
  - `phi_rate` can tolerate light filtering
  - `length_rate` is the clearest candidate for stronger filtering
  - `phi` and `length` themselves do not currently justify extra low-pass filtering

### Next Useful Test

- If the next goal is parameter finalization, the most useful follow-up is:
  1. repeat one small/slow dynamic run
  2. repeat one slightly faster dynamic run
- That will let us judge not only noise suppression, but also whether the chosen cutoff introduces unacceptable delay.

## 2026-06-28 LPF Validation Pass

### Scope

- Data files:
  - [joints_static_lpf.summary.txt](/mnt/d/STM32%20depository/stm32item/wheel_leg_ws/logs/stm32_state_capture/joints_static_lpf.summary.txt)
  - [joints_dynamic_lpf.summary.txt](/mnt/d/STM32%20depository/stm32item/wheel_leg_ws/logs/stm32_state_capture/joints_dynamic_lpf.summary.txt)
  - [joints_static_lpf.csv](/mnt/d/STM32%20depository/stm32item/wheel_leg_ws/logs/stm32_state_capture/joints_static_lpf.csv)
  - [joints_dynamic_lpf.csv](/mnt/d/STM32%20depository/stm32item/wheel_leg_ws/logs/stm32_state_capture/joints_dynamic_lpf.csv)
- Sampling rate remained near `200 Hz`.
- Capture quality remained healthy:
  - `crc_errors = 0`
  - `length_errors = 0`
  - `sync_losses = 0`

### Main Findings

- `joint_vel` low-pass is active and effective.
  - In static data, joint velocity std drops to about `60% ~ 66%` of raw for hip and knee.
  - In dynamic data, low-frequency motion below about `3 Hz` is almost fully preserved.
  - High-frequency power above about `20 Hz` is strongly attenuated, while motion-band content is mostly kept.
- `phi_rate` filtering is clearly effective and still looks acceptable.
  - Dynamic std drops to about `68% ~ 72%` of raw.
  - Motion below about `3 Hz` is preserved, while `10 Hz+` content is heavily reduced.
- `length_rate` filtering is the strongest and is doing the most useful cleanup.
  - In static data, std drops to about `23% ~ 24%` of raw.
  - In dynamic data, low-frequency content is preserved, but `10 Hz+` content is reduced to about `10%` of raw power.

### Delay / Over-Filtering Check

- `joint_vel`:
  - estimated delay is about `5 ms` for hip and knee, about `10 ms` for wheel
  - dynamic 99% span stays at about `96% ~ 100%` of raw
  - conclusion: not obviously over-filtered
- `phi_rate`:
  - no obvious whole-sample lag from correlation check
  - dynamic 99% span is about `62%` of raw
  - conclusion: filtering is noticeable but still reasonable
- `length_rate`:
  - no obvious whole-sample lag from correlation check
  - dynamic 99% span is about `62%` of raw
  - conclusion: strong filtering, but still not clearly excessive for this signal class

### Suspected Weak / Strong Areas

- `joint_vel` is not under-filtered in the frequency domain:
  - dynamic `20 ~ 50 Hz` power is already reduced to about `19% ~ 26%` for hip/knee
  - wheel velocity is filtered even more strongly in high frequency
- `joint_vel` is also not obviously over-filtered:
  - dynamic main motion amplitude is nearly unchanged
  - delay remains within about `1 ~ 2` samples at `200 Hz`
- `phi_rate` is close to the upper edge of what should be tolerated:
  - static noise drops well
  - dynamic motion peaks are visibly rounded
  - if this feeds a sensitive feedback loop, consider slightly relaxing cutoff
- `length_rate` is the most aggressive filter:
  - this is justified by the raw noise level
  - if faster leg-length transients matter later, this channel is the first one worth re-checking

### Practical Conclusion

- Current LPF looks effective overall.
- No channel shows clear evidence of "filtered too much" in the present logs.
- No channel shows clear evidence of "filtering not enough" either.
- The only channels worth close follow-up are:
  - `phi_rate`: maybe slightly strong
  - `length_rate`: intentionally strong, acceptable for now

### Next Best Validation

- To finalize cutoffs with more confidence, the most useful next log is a deliberately faster but still controlled motion test.
- Focus on whether:
  - `phi_rate_lpf` peak timing starts to lag real motion
  - `length_rate_lpf` misses narrow transients
  - `joint_vel` remains smooth without making the actuator feel soft

## 2026-06-28 Dynamic LPF Tuning Update

### Scope

- Data files:
  - [joints_dynamic_lpf_fast.summary.txt](/home/tan/wheel%20_leg_ws/logs/stm32_state_capture/joints_dynamic_lpf_fast.summary.txt)
  - [joints_dynamic_lpf_slow.summary.txt](/home/tan/wheel%20_leg_ws/logs/stm32_state_capture/joints_dynamic_lpf_slow.summary.txt)
- `slow` and `fast` use the same filter parameters.
- The difference is excitation speed only:
  - `slow`: manually moved motors slowly
  - `fast`: manually moved motors quickly

### What The New Data Showed

- Current `hip_vel` and `knee_vel` filtering is not obviously over-filtered:
  - typical lag stayed around one sample at `200 Hz`, about `5 ms`
  - motion peaks were still mostly preserved
- Current `fast` run suggests hip/knee filtering is still slightly light:
  - dynamic standard deviation changed very little
  - visible motion is preserved, but spike suppression during fast movement is limited
- Current `wheel_vel` filtering is stronger than hip/knee and already starts to compress peaks in `slow`:
  - wheel velocity should stay separately tuned
  - it should not be increased together with hip/knee
- `phi_rate` filtering looks acceptable as a light filter:
  - it reduces rate noise without obvious large delay
- `length_rate` is the heaviest filter in the current stack:
  - noise reduction is clear
  - but fast transients are being suppressed more aggressively than the other rate channels

### Updated Parameter Decision

- Keep the same filter structure.
- Adjust only default alpha values in `wheel_leg_stm32_bridge`.
- New defaults chosen as a compromise between the `slow` and `fast` runs:
  - `hip_velocity_low_pass_alpha`: `0.57 -> 0.60`
  - `knee_velocity_low_pass_alpha`: `0.62 -> 0.65`
  - `wheel_velocity_low_pass_alpha`: `0.73 -> 0.68`
  - `phi_rate_low_pass_alpha`: `0.57 -> 0.60`
  - `length_rate_low_pass_alpha`: `0.73 -> 0.70`
  - `body_velocity_low_pass_alpha`: keep `0.73`

### Rationale

- `hip_vel`:
  - slightly stronger than before to better suppress fast-run spikes
  - still intended to remain responsive
- `knee_vel`:
  - keep slightly stronger than hip because knee velocity remains noisier
- `wheel_vel`:
  - back off a little from the previous setting because slow-run peak compression was already visible
- `phi_rate`:
  - move to a slightly steadier setting while keeping it in the light-filter category
- `length_rate`:
  - reduce filter strength slightly because the previous setting was the closest to over-filtering in fast transitions
- `body_velocity`:
  - keep unchanged for now because it directly affects wheel-related closed-loop behavior and no stronger evidence suggests retuning it yet

### Next Check

- Re-run the same `slow` and `fast` manual-motion tests with the new defaults.
- Focus on:
  - whether hip/knee spikes are reduced in `fast`
  - whether wheel velocity peaks stay less compressed in `slow`
  - whether `length_rate` recovers more useful transient content without becoming visibly noisy

## 2026-06-28 Dynamic LPF Tuning Follow-Up

### Scope

- Data files:
  - [joints_dynamic_lpf_fast.summary.txt](/home/tan/wheel%20_leg_ws/logs/stm32_state_capture/joints_dynamic_lpf_fast.summary.txt)
  - [joints_dynamic_lpf_slow.summary.txt](/home/tan/wheel%20_leg_ws/logs/stm32_state_capture/joints_dynamic_lpf_slow.summary.txt)
- These runs were taken after the first round of default LPF updates:
  - `hip_velocity_low_pass_alpha = 0.60`
  - `knee_velocity_low_pass_alpha = 0.65`
  - `wheel_velocity_low_pass_alpha = 0.68`
  - `phi_rate_low_pass_alpha = 0.60`
  - `length_rate_low_pass_alpha = 0.70`

### What Improved

- `hip_vel` and `knee_vel` stayed responsive:
  - slow-run lag remained about `5 ms`
  - fast-run lag stayed in the light-filter range, about `10 ms`
  - no clear sign of over-filtering
- `wheel_vel` improved relative to the previous setting:
  - slow-run peak compression became noticeably milder
  - wheel velocity now looks closer to the intended compromise between noise suppression and responsiveness
- `phi_rate` remained acceptable as a light filter:
  - useful smoothing is present
  - no strong evidence of excessive delay

### What Still Looks Conservative

- `length_rate` is still the strongest filter in the current group:
  - dynamic standard deviation is still reduced heavily
  - fast-transition peaks are still compressed much more than the other rate channels
- This means:
  - for observation-only use, the current setting is still usable
  - for judging fast transient leg extension/retraction behavior, it is still somewhat too conservative

### Updated Decision

- Keep these unchanged:
  - `hip_velocity_low_pass_alpha = 0.60`
  - `knee_velocity_low_pass_alpha = 0.65`
  - `wheel_velocity_low_pass_alpha = 0.68`
  - `phi_rate_low_pass_alpha = 0.60`
  - `body_velocity_low_pass_alpha = 0.73`
- Adjust only:
  - `length_rate_low_pass_alpha: 0.70 -> 0.67`

### Rationale

- The latest retest suggests the first parameter update already fixed the more obvious wheel-velocity issue.
- The main remaining candidate for improvement is `length_rate`.
- Changing only one parameter in the next round makes the next comparison easier to interpret.
- `0.67` is intended as a small step, not a large jump:
  - recover a bit more transient content
  - avoid immediately exposing too much differentiated noise

### Next Check

- Re-run the same manual `slow` and `fast` tests with only `length_rate_low_pass_alpha = 0.67` changed.
- Focus on:
  - whether `length_rate_lpf` retains more transient structure in `fast`
  - whether `length_rate_lpf` remains visually cleaner than raw in `slow`
  - whether the leg-length-rate channel becomes more useful without becoming obviously spiky

## 2026-06-28 Dynamic LPF Tuning Follow-Up 2

### Scope

- Data files:
  - [joints_dynamic_lpf_fast.summary.txt](/home/tan/wheel%20_leg_ws/logs/stm32_state_capture/joints_dynamic_lpf_fast.summary.txt)
  - [joints_dynamic_lpf_slow.summary.txt](/home/tan/wheel%20_leg_ws/logs/stm32_state_capture/joints_dynamic_lpf_slow.summary.txt)
- This round changed only:
  - `length_rate_low_pass_alpha: 0.70 -> 0.67`

### What Changed

- `hip_vel`, `knee_vel`, `wheel_vel`, `phi_rate`, and `body_velocity` remained in the same practical range as the previous round.
- `length_rate` did move in the intended direction, but only slightly:
  - filtered standard deviation increased a little relative to raw
  - some transient content was recovered
  - however, the effect was still modest

### Practical Reading

- The `0.67` setting appears safe:
  - it did not create an obvious noise explosion
  - it did not introduce a new visible problem in the other channels
- But `0.67` still looks conservative for `length_rate`:
  - peak retention is still much lower than the other rate-like channels
  - transition detail is still more suppressed than desired

### Updated Decision

- Keep unchanged:
  - `hip_velocity_low_pass_alpha = 0.60`
  - `knee_velocity_low_pass_alpha = 0.65`
  - `wheel_velocity_low_pass_alpha = 0.68`
  - `phi_rate_low_pass_alpha = 0.60`
  - `body_velocity_low_pass_alpha = 0.73`
- Adjust only:
  - `length_rate_low_pass_alpha: 0.67 -> 0.62`

### Rationale

- The previous step was likely too small to create a clearly readable improvement.
- The main unresolved issue is still `length_rate` transient suppression.
- A larger single-step change is more useful now than another tiny nudge, because:
  - it should produce a more visible difference in the next `slow/fast` comparison
  - it still keeps the test isolated to one parameter

### Next Check

- Re-run the same `slow` and `fast` manual-motion tests with only `length_rate_low_pass_alpha = 0.62`.
- Focus on:
  - whether `length_rate_lpf` becomes meaningfully closer to the raw transition shape
  - whether the channel stays interpretable in `slow`
  - whether the noise increase is acceptable for the intended downstream use

## 2026-06-28 Dynamic LPF Tuning Follow-Up 3

### Scope

- Data files:
  - [joints_dynamic_lpf_fast.summary.txt](/home/tan/wheel%20_leg_ws/logs/stm32_state_capture/joints_dynamic_lpf_fast.summary.txt)
  - [joints_dynamic_lpf_slow.summary.txt](/home/tan/wheel%20_leg_ws/logs/stm32_state_capture/joints_dynamic_lpf_slow.summary.txt)
- This round changed only:
  - `length_rate_low_pass_alpha: 0.67 -> 0.62`

### Result

- `hip_vel`, `knee_vel`, `wheel_vel`, `phi_rate`, and `body_velocity` remained in a stable and acceptable range.
- `length_rate` became more open than the `0.67` setting:
  - more transient structure is visible
  - dynamic attenuation is reduced compared with the previous round
- The tradeoff is expected:
  - low-motion noise increased somewhat
  - but it did not become obviously unusable in this manual-motion test

### Practical Conclusion

- `length_rate_low_pass_alpha = 0.62` is a reasonable stopping point for now.
- It is a better compromise than `0.67` if the goal is to observe leg-length-rate transitions more clearly.
- It does not currently justify another immediate reduction, because:
  - additional transient recovery will likely come with disproportionately more noise
  - the next more useful validation step is no longer manual motion, but real closed-loop or close-to-real actions

### Current Recommended Default Set

- `hip_velocity_low_pass_alpha = 0.60`
- `knee_velocity_low_pass_alpha = 0.65`
- `wheel_velocity_low_pass_alpha = 0.68`
- `phi_rate_low_pass_alpha = 0.60`
- `length_rate_low_pass_alpha = 0.62`
- `body_velocity_low_pass_alpha = 0.73`

## How To Validate On Real Actions

### Goal

- The next objective is not only to compare raw-vs-filtered smoothness.
- The real question is whether these signals remain useful when the robot is doing meaningful tasks:
  - standing balance
  - small forward/backward wheel motion
  - squat-like leg length change
  - small disturbance recovery

### Recommended Test Order

1. Closed-loop stand with no intentional command input for a short hold.
2. Closed-loop stand with small forward/backward velocity commands.
3. Closed-loop stand with small leg-length reference changes if available.
4. A slightly more dynamic but still safe maneuver, such as gentle start-stop or mild push recovery.

### What To Record

- Keep recording the same filtered and raw channels when possible.
- The most useful channels to compare together are:
  - `left/right_hip_vel_raw` vs `left/right_hip_vel`
  - `left/right_knee_vel_raw` vs `left/right_knee_vel`
  - `left/right_wheel_vel_raw` vs `left/right_wheel_vel`
  - `left/right_phi_rate_raw` vs `left/right_phi_rate_lpf`
  - `left/right_length_rate_raw` vs `left/right_length_rate_lpf`
  - `body_velocity_raw` vs `body_velocity`
- During closed-loop tests, also pay attention to related behavior signals:
  - `pitch`
  - `pitch_rate`
  - wheel torque / wheel effort
  - hip torque / hip effort
  - commanded velocity or leg-length reference if available
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

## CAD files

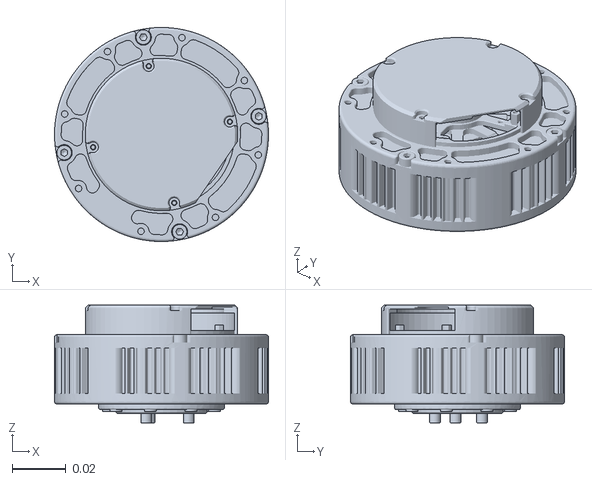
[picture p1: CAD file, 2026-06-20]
sim/mujoco/assets/right_thigh__joint_motor_assembly_1.stl
0.08 x 0.08 x 0.044

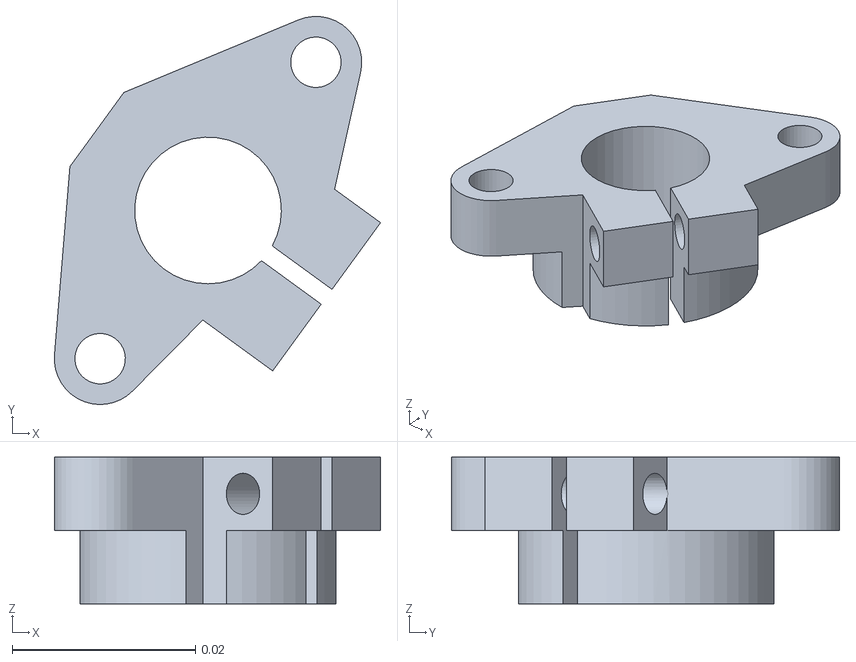
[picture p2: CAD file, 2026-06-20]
sim/mujoco/assets/zong_zhuang____left_thigh_1_16_zhi_cheng_jia__2.stl
0.0356 x 0.0423 x 0.016

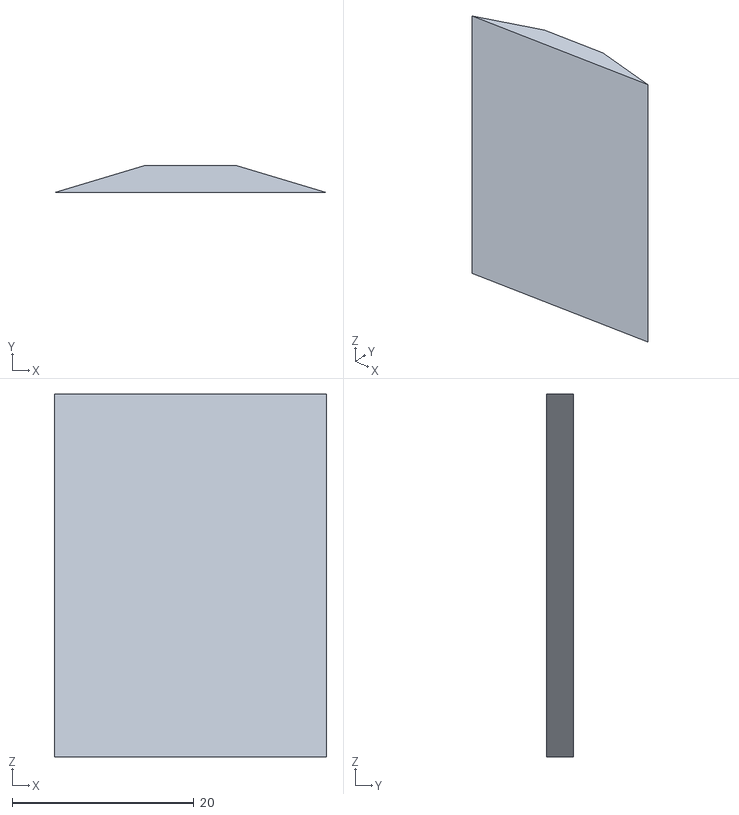
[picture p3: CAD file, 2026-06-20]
transplant/matlab_sim/source/steps/3.STL
30.0 x 3.00 x 40.0

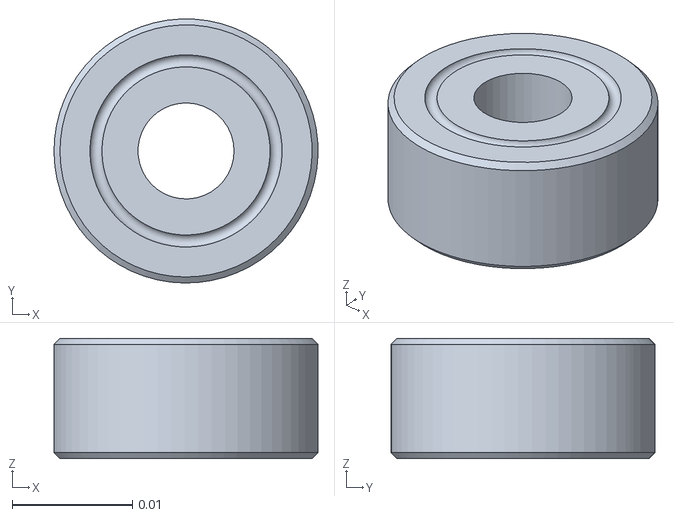
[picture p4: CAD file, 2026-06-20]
sim/mujoco/assets/zong_zhuang____left_connect2_1__zhou_cheng_8_22_10_2.stl
0.022 x 0.022 x 0.01

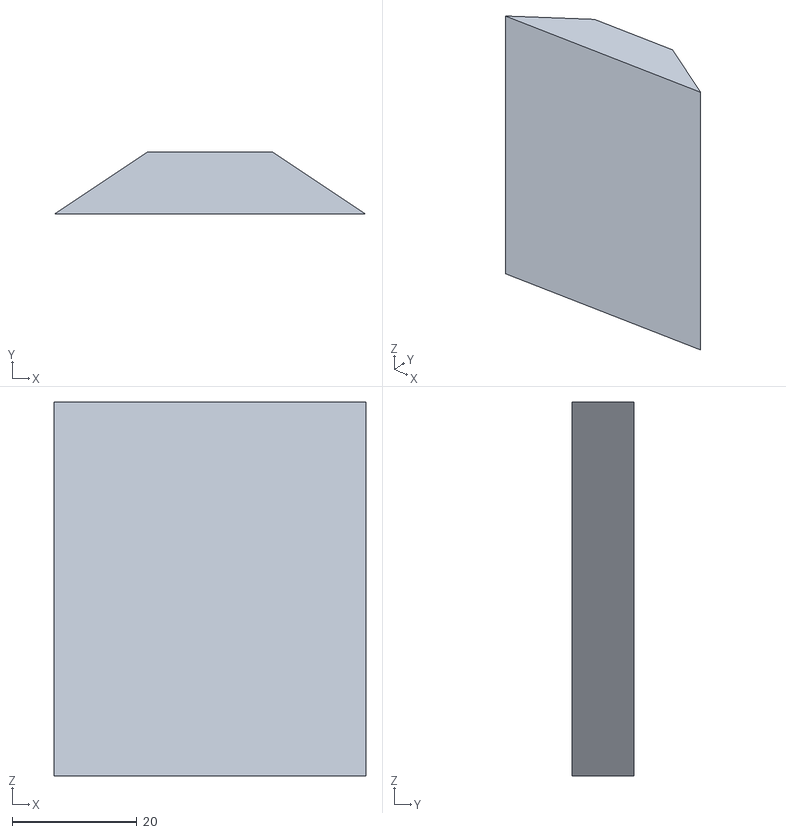
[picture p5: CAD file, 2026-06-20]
transplant/matlab_sim/source/steps/slower.STL
50.0 x 10.00 x 60.0

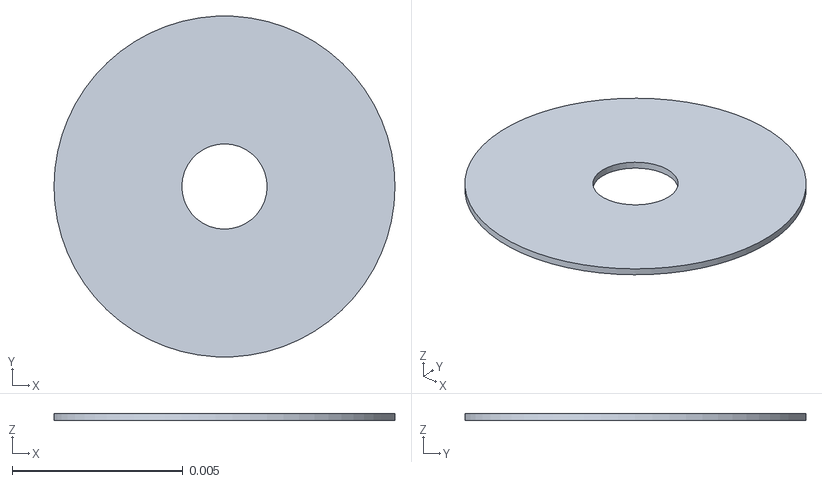
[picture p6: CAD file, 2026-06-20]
sim/mujoco/assets/zong_zhuang____right_connect2_2__dian_pian__m3_10_1_2.stl
0.01 x 0.00999 x 0.0002

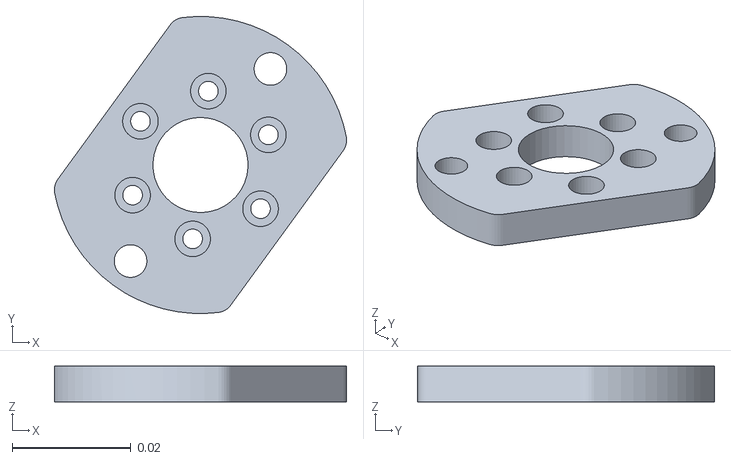
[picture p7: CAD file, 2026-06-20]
sim/mujoco/assets/zong_zhuang____left_thigh_1__fa_lan_dian_kuai_jie_pian__1_1.stl
0.0492 x 0.05 x 0.006

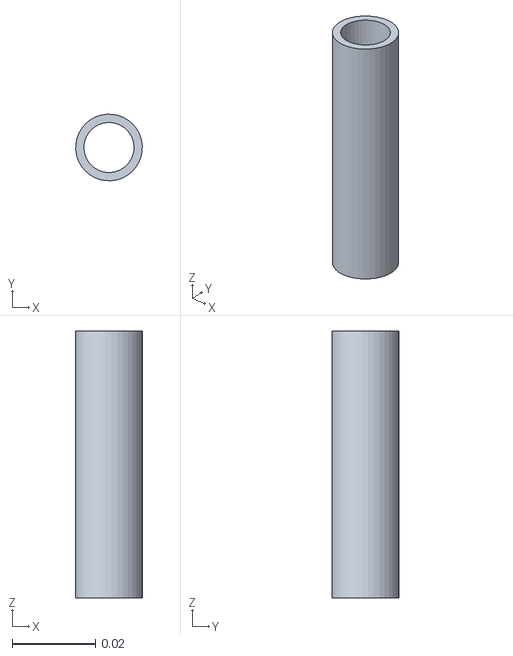
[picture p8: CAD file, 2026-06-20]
sim/mujoco/assets/zong_zhuang____right_thigh_1__tan_guan__1.stl
0.016 x 0.016 x 0.064

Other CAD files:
sim/mujoco/assets/base__joint_motor_assembly_2.stl
sim/mujoco/assets/right_connect2__joint_motor_assembly_2.stl
sim/mujoco/assets/right_thigh__joint_motor_assembly_2.stl
sim/mujoco/assets/base__joint_motor_assembly_1.stl
sim/mujoco/assets/right_calf__joint_motor_assembly_2.stl
sim/mujoco/assets/right_wheel__joint_motor_assembly_2.stl
sim/mujoco/assets/left_thigh__joint_motor_assembly_1.stl
sim/mujoco/assets/right_connect1__joint_motor_assembly_2.stl
transplant/matlab_sim/source/steps/2.5.STL
sim/mujoco/assets/zong_zhuang____right_connect2_2__dian_pian__m3_10_1_4.stl
sim/mujoco/assets/zong_zhuang____base_1__di_ban__1.stl
sim/mujoco/assets/zong_zhuang____base_1__dian_chi__1.stl
sim/mujoco/assets/zong_zhuang____base_1__dian_chi__2.stl
sim/mujoco/assets/zong_zhuang____base_1__lv_fang_tong_100_20_200_2.stl
sim/mujoco/assets/zong_zhuang____base_1__lv_fang_tong_100_20_200_y_2.stl
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

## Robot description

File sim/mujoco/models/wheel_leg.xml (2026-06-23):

<?xml version="1.0" encoding="UTF-8"?>
<mujoco model="wheel_leg">
  <compiler angle="radian" meshdir="../assets"/>

  <option gravity="0 0 -9.81"/>

  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

  <default>
    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
    <default class="base_default"/>
    <default class="left_thigh_default"/>
    <default class="right_thigh_default"/>
    <default class="left_connect1_default"/>
    <default class="right_connect1_default"/>
    <default class="left_connect2_default"/>
    <default class="right_connect2_default"/>
    <default class="left_calf_default"/>
    <default class="right_calf_default"/>
    <default class="left_wheel_default"/>
    <default class="right_wheel_default"/>
  </default>
  

  <worldbody>
    <light name="top" pos="0 0 2"/>

    <body name="base_body" pos="0 0 0.3">
      <freejoint/>
      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

      <body name="left_thigh_body" pos="-0.0775 0.04425 -0.02 " euler="-1.5708 0 -1.5708">
        <joint name="left_hip_joint" type="hinge" pos="0 0 0" axis="0 0 1"/>

        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
        
        <body name="left_connect1_body" pos="0 0 0.1235">
          <joint name="left_knee_joint" type="hinge" pos="0 0 0" axis="0 0 1"/>

          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

          <body name="left_connect2_body" pos="-0.02195 0.04493 0.01225">
            <joint name="left_connect2_joint" type="hinge" pos="0 0 0" axis="0 0 1"/>
            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
          </body>
        </body>
        <body name="left_calf_body" pos="-0.10594 -0.14552 0.12455" euler="0 0 3.14159">
          <joint name="left_calf_joint" type="hinge" pos="0 0 0" axis="0 0 1"/>
          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

          <body name="left_wheel_body" pos="0.09885 -0.20207 0.04907">
            <joint name="left_wheel_joint" type="hinge" pos="0 0 0" axis="0 0 1"/>
            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
          </body> 
        </body>
      </body>

      
      <body name="right_thigh_body" pos="-0.0775 -0.04425 -0.02 " euler="-1.5708 0 -1.5708">
        <joint name="right_hip_joint" type="hinge" pos="0 0 0" axis="0 0 1"/>
        
        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

        <body name="right_connect1_body" pos="0 0 -0.1235" euler="3.14159 0 0">
          <joint name="right_knee_joint" type="hinge" pos="0 0 0" axis="0 0 -1"/>
          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 
           
          <body name="right_connect2_body" pos="-0.02785 -0.04153 0.01225" euler="3.14159 0 0">
            <joint name="right_connect2_joint" type="hinge" pos="0 0 0" axis="0 0 1"/>
            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
          </body>
        </body>

        <body name="right_calf_body" pos="-0.10179 -0.14845 -0.12525" euler="0 0 3.14159">
          <joint name="right_calf_joint" type="hinge" pos="0 0 0" axis="0 0 1"/>
          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
        
          <body name="right_wheel_body" pos="0.12519 -0.18690 -0.04280">
            <joint name="right_wheel_joint" type="hinge" pos="0 0 0" axis="0 0 1"/>
            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
          </body>
        </body>
      </body>
    </body>
  </worldbody>

  <actuator>
    <motor name="left_hip_motor" joint="left_hip_joint" gear="1" ctrllimited="true" ctrlrange="-400 400"/>

    <motor name="right_hip_motor" joint="right_hip_joint" gear="1" ctrllimited="true" ctrlrange="-400 400"/>

    <motor name="left_knee_motor" joint="left_knee_joint" gear="1" ctrllimited="true" ctrlrange="-400 400"/>

    <motor name="right_knee_motor" joint="right_knee_joint" gear="1" ctrllimited="true" ctrlrange="-400 400"/>

    <motor name="left_wheel_motor" joint="left_wheel_joint" gear="1" ctrllimited="true" ctrlrange="-400 400"/>

    <motor name="right_wheel_motor" joint="right_wheel_joint" gear="1" ctrllimited="true" ctrlrange="-400 400"/> 
  </actuator>

  <sensor>
    <accelerometer name="base_accel" site="base_frame"/>
    <gyro name="base_gyro" site="base_frame"/>
    <framequat name="base_quat" objtype="site" objname="base_frame"/>

    <jointpos name="left_hip_encoder" joint="left_hip_joint"/>
    <jointvel name="left_hip_encoder_vel" joint="left_hip_joint"/>
    <jointpos name="right_hip_encoder" joint="right_hip_joint"/>
    <jointvel name="right_hip_encoder_vel" joint="right_hip_joint"/>

    <jointpos name="left_knee_encoder" joint="left_knee_joint"/>
    <jointvel name="left_knee_encoder_vel" joint="left_knee_joint"/>
    <jointpos name="right_knee_encoder" joint="right_knee_joint"/>
    <jointvel name="right_knee_encoder_vel" joint="right_knee_joint"/>

    <jointpos name="left_wheel_encoder" joint="left_wheel_joint"/>
    <jointvel name="left_wheel_encoder_vel" joint="left_wheel_joint"/>
    <jointpos name="right_wheel_encoder" joint="right_wheel_joint"/>
    <jointvel name="right_wheel_encoder_vel" joint="right_wheel_joint"/>

    <jointpos name="left_calf_encoder" joint="left_calf_joint"/>
    <jointvel name="left_calf_encoder_vel" joint="left_calf_joint"/>
    <jointpos name="right_calf_encoder" joint="right_calf_joint"/>
    <jointvel name="right_calf_encoder_vel" joint="right_calf_joint"/>
  </sensor> 

  <equality>
    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
    <connect site1="left_connect2_site" site2="left_calf_site" />
    <connect site1="right_connect2_site" site2="right_calf_site" />
  </equality>


</mujoco>

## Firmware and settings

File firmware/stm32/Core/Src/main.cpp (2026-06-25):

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
/* Includes ------------------------------------------------------------------*/
#include "main.h"
#include "dma.h"
#include "fdcan.h"
#include "memorymap.h"
#include "tim.h"
#include "usart.h"
#include "gpio.h"
/* USER CODE BEGIN Includes */
#include "Car.h"
/* USER CODE END Includes */


void SystemClock_Config(void);
static void MPU_Config(void);
/**
  * @brief  The application entry point.
  * @retval int
  */
int main(void)
{

  /* MPU Configuration--------------------------------------------------------*/
  MPU_Config();

  /* MCU Configuration--------------------------------------------------------*/

  /* Reset of all peripherals, Initializes the Flash interface and the Systick. */
  HAL_Init();

  /* Configure the system clock */
  SystemClock_Config();

  /* Initialize all configured peripherals */
    MX_GPIO_Init();
    MX_DMA_Init();
    MX_FDCAN1_Init();
    MX_USART1_UART_Init();
    MX_USART2_UART_Init();
    MX_USART3_UART_Init();
    MX_TIM3_Init();
    MX_TIM2_Init();
  /* USER CODE BEGIN 2 */
    
    Car_Init();
  /* USER CODE END 2 */

  /* Infinite loop */
  /* USER CODE BEGIN WHILE */
  while (1)
  {
    /* USER CODE END WHILE */

    /* USER CODE BEGIN 3 */
  }
  /* USER CODE END 3 */
}

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
 /* MPU Configuration */

void MPU_Config(void)
{
  MPU_Region_InitTypeDef MPU_InitStruct = {0};

  /* Disables the MPU */
  HAL_MPU_Disable();

  /** Initializes and configures the Region and the memory to be protected
  */
  MPU_InitStruct.Enable = MPU_REGION_ENABLE;
  MPU_InitStruct.Number = MPU_REGION_NUMBER0;
  MPU_InitStruct.BaseAddress = 0x0;
  MPU_InitStruct.Size = MPU_REGION_SIZE_4GB;
  MPU_InitStruct.SubRegionDisable = 0x87;
  MPU_InitStruct.TypeExtField = MPU_TEX_LEVEL0;
  MPU_InitStruct.AccessPermission = MPU_REGION_NO_ACCESS;
  MPU_InitStruct.DisableExec = MPU_INSTRUCTION_ACCESS_DISABLE;
  MPU_InitStruct.IsShareable = MPU_ACCESS_SHAREABLE;
  MPU_InitStruct.IsCacheable = MPU_ACCESS_NOT_CACHEABLE;
  MPU_InitStruct.IsBufferable = MPU_ACCESS_NOT_BUFFERABLE;

  HAL_MPU_ConfigRegion(&MPU_InitStruct);
  /* Enables the MPU */
  HAL_MPU_Enable(MPU_PRIVILEGED_DEFAULT);

}



/**
  * @brief  This function is executed in case of error occurrence.
  * @retval None
  */
void Error_Handler(void)
{
  /* USER CODE BEGIN Error_Handler_Debug */
  /* User can add his own implementation to report the HAL error return state */
  __disable_irq();
  while (1)
  {
  }
  /* USER CODE END Error_Handler_Debug */
}

#ifdef  USE_FULL_ASSERT
/**
  * @brief  Reports the name of the source file and the source line number
  *         where the assert_param error has occurred.
  * @param  file: pointer to the source file name
  * @param  line: assert_param error line source number
  * @retval None
  */
void assert_failed(uint8_t *file, uint32_t line)
{
  /* USER CODE BEGIN 6 */
  /* User can add his own implementation to report the file name and line number,
     ex: printf("Wrong parameters value: file %s on line %d\r\n", file, line) */
  /* USER CODE END 6 */
}
#endif /* USE_FULL_ASSERT */

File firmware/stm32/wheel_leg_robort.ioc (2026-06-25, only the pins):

Mcu.UserName=STM32H743VITx
PA10.Signal=USART1_RX
PA2.Signal=USART2_TX
PA3.Signal=USART2_RX
PA9.Signal=USART1_TX
PB10.Signal=USART3_TX
PB11.Signal=USART3_RX
PB6.GPIO_Label=SDA
PB6.Signal=GPIO_Output
PB7.GPIO_Label=SCL
PB7.Signal=GPIO_Output
PD0.Signal=FDCAN1_RX
PD1.Signal=FDCAN1_TX

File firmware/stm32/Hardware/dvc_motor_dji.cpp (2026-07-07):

/**
 * @file dvc_motor_dji.cpp
 * @author yssickjgd (1345578933@qq.com)
 * @brief 大疆电机配置与操作
 * @version 1.2
 * @date 2023-08-29 0.1 23赛季定稿
 * @date 2024-01-01 1.1 官方6020驱动更新, 适配电压控制与电流控制
 * @date 2024-03-07 1.2 新增功率控制接口与相关函数, 24赛季定稿
 * @date 2025-12-03 2.1 彻底抛弃6020电压控制版本, 仅保留电流控制版本
 *
 * @copyright USTC-RoboWalker (c) 2023-2025
 *
 */

/* Includes ------------------------------------------------------------------*/

#include "dvc_motor_dji.h"

/* Private macros ------------------------------------------------------------*/

/* Private types -------------------------------------------------------------*/

/* Private variables ---------------------------------------------------------*/

/* Private function declarations ---------------------------------------------*/

namespace
{
static const float kDegToRad = PI / 180.0f;

static float g_left_hip_world_angle = 0.0f;
static float g_right_hip_world_angle = 0.0f;
static float g_left_hip_world_omega = 0.0f;
static float g_right_hip_world_omega = 0.0f;

float NormalizeAnglePositive(float angle)
{
    while (angle < 0.0f)
    {
        angle += 2.0f * PI;
    }
    while (angle >= 2.0f * PI)
    {
        angle -= 2.0f * PI;
    }
    return angle;
}

void MapGIM6010AngleToLegFrame(const Enum_Motor_DJI_ID can_id,
                               const float motor_angle,
                               const float motor_omega,
                               float *mapped_angle,
                               float *mapped_omega)
{
    // Calibration from leg_data.txt:
    // World angle convention: horizontal +X is 0 deg, clockwise is positive.
    // Vertical downward is 90 deg and vertical upward is 270 deg.
    // Hip calibration pose maps both sides to 190.81 deg in world frame.
    // Knee calibration pose maps link angle magnitude 63.86 deg to -63.86 deg
    // in the current relative-angle convention.
    // Knee motors are mounted on hip_link, so knee world angle is:
    // hip_world_angle + knee_relative_angle + knee_offset.
    switch (can_id)
    {
    case CAN_Motor_ID_0x4E:
        *mapped_angle = NormalizeAnglePositive(-motor_angle + 190.81f * kDegToRad);
        *mapped_omega = -motor_omega;
        g_left_hip_world_angle = *mapped_angle;
        g_left_hip_world_omega = *mapped_omega;
        break;
    case CAN_Motor_ID_0x2E:
        *mapped_angle = NormalizeAnglePositive(motor_angle + 127.758f * kDegToRad);
        *mapped_omega = motor_omega;
        g_right_hip_world_angle = *mapped_angle;
        g_right_hip_world_omega = *mapped_omega;
        break;
    case CAN_Motor_ID_0x6E:
    {
        const float knee_relative_angle = -motor_angle - 68.491f * kDegToRad;
        *mapped_angle = NormalizeAnglePositive(g_left_hip_world_angle +
                                               knee_relative_angle);
        *mapped_omega = g_left_hip_world_omega - motor_omega;
        break;
    }
    case CAN_Motor_ID_0x8E:
    {
        const float knee_relative_angle = motor_angle - 68.538f * kDegToRad;
        *mapped_angle = NormalizeAnglePositive(g_right_hip_world_angle +
                                               knee_relative_angle);
        *mapped_omega = g_right_hip_world_omega + motor_omega;
        break;
    }
    default:
        *mapped_angle = motor_angle;
        *mapped_omega = motor_omega;
        break;
    }
}
} // namespace

/* Function prototypes -------------------------------------------------------*/

// TX buffer mapping for current project: FDCAN1 only.
uint8_t *allocate_tx_data(const FDCAN_HandleTypeDef *hcan,
                          const Enum_Motor_DJI_ID &__CAN_ID)
{
    uint8_t *tmp_tx_data_ptr = 0;

    if (hcan != &hfdcan1)
    {
        return (0);
    }

    switch (__CAN_ID)
    {
    case Motor_DJI_ID_0x201:
        tmp_tx_data_ptr = &(CAN1_0x200_Tx_Data[0]);
        break;
    case Motor_DJI_ID_0x202:
        tmp_tx_data_ptr = &(CAN1_0x200_Tx_Data[2]);
        break;
    case (CAN_Motor_ID_0x2E):
        tmp_tx_data_ptr = &(CAN1_0x2E_Tx_Data[0]);
        break;
    case (CAN_Motor_ID_0x4E):
        tmp_tx_data_ptr = &(CAN1_0x4E_Tx_Data[0]);
        break;
    case (CAN_Motor_ID_0x6E):
        tmp_tx_data_ptr = &(CAN1_0x6E_Tx_Data[0]);
        break;
    case (CAN_Motor_ID_0x8E):
        tmp_tx_data_ptr = &(CAN1_0x8E_Tx_Data[0]);
    default:
        break;
    }

    return (tmp_tx_data_ptr);
}

/**
 * @brief 电机初始化
 *
 * @param hcan 绑定的CAN总线
 * @param __CAN_Rx_ID 绑定的CAN ID
 * @param __Motor_DJI_Control_Method 电机控制方式, 默认角度
 * @param __Angle_Offset 角度零点偏置, rad
 */
void Class_Motor_DJI_GIM6010::Init(const FDCAN_HandleTypeDef *hcan, const Enum_Motor_DJI_ID &__CAN_Rx_ID, const float &__Angle_Offset)
{
    CAN_Manage_Object = &CAN1_Manage_Object;
    CAN_Rx_ID = __CAN_Rx_ID;
    Angle_Offset = __Angle_Offset;
    Tx_Data = allocate_tx_data(hcan, __CAN_Rx_ID);
    uint8_t mode_data1[8] = {0x01, 0x00, 0x00, 0x00, 0x01, 0x00, 0x00, 0x00};
    uint8_t mode_data2[8] = {0x08, 0x00, 0x00, 0x00, 0x00, 0x00, 0x00, 0x00};
    CAN_Transmit_Data((FDCAN_HandleTypeDef *) hcan, __CAN_Rx_ID<<5|0xB, mode_data1, 8);
    CAN_Transmit_Data((FDCAN_HandleTypeDef *) hcan, __CAN_Rx_ID<<5|0x7, mode_data2, 8);

}

void Class_Motor_DJI_GIM6010::CAN_RxCpltCallback(uint8_t data_id)
{
    Flag += 1;
    Data_Process(data_id);
}

void Class_Motor_DJI_GIM6010::TIM_100ms_Alive_PeriodElapsedCallback()
{
    if (Flag == Pre_Flag)
    {
        Motor_DJI_Status = Motor_DJI_Status_DISABLE;
    }
    else
    {
        Motor_DJI_Status = Motor_DJI_Status_ENABLE;
    }
    Pre_Flag = Flag;
}

void Class_Motor_DJI_GIM6010::TIM_Calculate_PeriodElapsedCallback()
{
    Out = Target_Torque/8.0f;
    // Basic_Math_Constrain(&Out, -OUT_MAX, OUT_MAX);

    Output();
    
    Feedforward_Torque = 0.0f;
}

void Class_Motor_DJI_GIM6010::Data_Process(uint8_t data_id)
{
    uint8_t *tmp_buffer = CAN_Manage_Object->Rx_Buffer;
    if ((data_id & 0x0F) == 0x09)
    {
        uint32_t angle_bits = (static_cast<uint32_t>(tmp_buffer[3]) << 24) |
                              (static_cast<uint32_t>(tmp_buffer[2]) << 16) |
                              (static_cast<uint32_t>(tmp_buffer[1]) << 8) |
                              static_cast<uint32_t>(tmp_buffer[0]);
        const float motor_angle =
            Math_BitsToFloat(angle_bits) / 4.0f * PI - Angle_Offset;
        const float motor_omega =
            Math_BitsToFloat((tmp_buffer[7] << 24) | (tmp_buffer[6] << 16) |
                             (tmp_buffer[5] << 8) | tmp_buffer[4]) *
            4.0f * PI / 15.0f;
        MapGIM6010AngleToLegFrame(CAN_Rx_ID, motor_angle, motor_omega,
                                  &Rx_Data.Now_Angle, &Rx_Data.Now_Omega);
    }
    else if ((data_id & 0x0F) == 0x0C)
    {
        Rx_Data.Now_Torque = Math_BitsToFloat((tmp_buffer[7] << 24) | (tmp_buffer[6] << 16) | (tmp_buffer[5] << 8) | tmp_buffer[4]);
    }
}
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

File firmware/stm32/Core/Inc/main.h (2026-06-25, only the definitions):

#define SDA_Pin GPIO_PIN_6
#define SDA_GPIO_Port GPIOB
#define SCL_Pin GPIO_PIN_7
#define SCL_GPIO_Port GPIOB

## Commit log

2026-06-20 写好mujoco和ros2桥接的文档,准备执行
2026-06-20 桥接mujoco和ros实现
2026-06-20 已经打通mujoco和ros的桥接
2026-06-20 仿真内的控制逻辑移出来
2026-06-21 完成mujoco和ros桥接
2026-06-21 开始接入遥控
2026-06-21 测试接收机和rpi通信成功
2026-06-21 完成映射
2026-06-21 仿真测试遥控映射
2026-06-21 完成遥控器验证
2026-06-23 修正稳态偏差
2026-06-23 移入stm32
2026-06-23 完成调参
2026-06-23 改工程结构
    [base__joint_motor_assembly_1.stl, base__joint_motor_assembly_2.stl, left_thigh__joint_motor_assembly_1.stl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]
2026-06-24 先弄硬件
2026-06-24 清理文档
2026-06-24 开始写ros和stm的通信
2026-06-25 stm测试代码
2026-06-25 ros侧测试
2026-06-25 在ros测测试丢包率
2026-06-25 补交树莓派
2026-06-25 ros侧测试通信
2026-06-25 记录文档
2026-06-25 正式通信
2026-06-25 修bug
2026-06-25 通信测试
2026-06-25 问题记录
2026-06-25 记录stm侧问题
2026-06-25 四u夫stm侧bug
2026-06-25 通信测试完成
2026-06-25 力矩测试
2026-06-25 测好力极性
2026-06-25 补交stm
2026-06-25 急停链路
2026-06-25 加入DMA
2026-06-25 整理代码
2026-06-25 ros侧代码整理
2026-06-25 限位保护
2026-06-25 关节限位保护
2026-06-26 100hz调参
2026-06-26 测完电机和限位
2026-06-26 传感器数据检测
2026-06-27 修正角度
2026-06-27 修正phi
2026-06-27 phi补
2026-06-27 测试state滤波
2026-06-27 修正脚本
2026-06-27 静态数据
    [imu_static.csv, joints_static.csv, leg_static.csv]
2026-06-27 清理树莓派
    [imu_static.csv, joints_static.csv, leg_static.csv]
2026-06-27 动态数据
    [joints_dynamic.csv, leg_dynamic.csv]
2026-06-27 低通后数据
    [joints_dynamic_lpf.csv, joints_static_lpf.csv]
2026-06-27 多测一组
2026-06-27 做完滤波
2026-07-02 调完滤波
2026-07-02 腿长调参
2026-07-02 运行测试
2026-07-02 修改极性
2026-07-02 修改pid极性
2026-07-02 修改vmc极性
2026-07-02 修正vmc
2026-07-02 修正vmc2
2026-07-02 修正vmc3
2026-07-03 改vmc
2026-07-03 调length pid
2026-07-03 改launch
2026-07-03 可用参数
2026-07-03 固定腿长参数
2026-07-03 跟进文档
2026-07-03 更新k增益
2026-07-03 lqrhip极性
2026-07-03 lqr_调试节点
2026-07-03 lqr_调试
2026-07-03 检测vmc
2026-07-07 修好lqr力矩输出
2026-07-07 修改力矩极性,解决hip抖动
2026-07-07 关了保护
2026-07-07 修正hip极性
2026-07-07 left knee极性
2026-07-07 重新标定
2026-07-07 修lqr
2026-07-08 准备调轮子

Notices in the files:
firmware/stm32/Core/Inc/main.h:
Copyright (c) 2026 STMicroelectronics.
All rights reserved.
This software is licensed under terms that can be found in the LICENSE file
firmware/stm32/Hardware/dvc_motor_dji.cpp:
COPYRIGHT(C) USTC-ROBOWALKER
